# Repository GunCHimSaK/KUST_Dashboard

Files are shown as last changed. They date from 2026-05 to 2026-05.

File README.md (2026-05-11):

# ☀️ KUST 2027 WSC - Dashboard

### Project info

2027 World Solar Challenge (27WSC)를 위한 태양광 자동차 대시보드 펌웨어입니다.

차량 내 핵심 데이터(Driving/Power, Battery BMS)들을 CAN 통신을 통해 데이터를 주고받으며, 주행 정보 및 에러 상태를 실시간으로 계기판 LCD에 띄우고 핸들에서 입력되는 다양한 버튼 데이터들을 각 부분에 전송합니다.

### **System Block Diagram**


### **Dashboard Screen**



### Hardware

- **MCU:** Nucleo U535CE
  
- **Clock:** 160MHz
  
- **IDE:** STM32CubeIDE
  
- **Tool:** LVGL, Square Line Studio
  
- **Communication:** FDCAN (Classic CAN Mode), LPUART1 (115200 bps, Debug)

###

### CAN Matrix

| | CAN ID | Group | Byte0 | Byte1 | Byte2 | Byte3 | Byte4 | Byte5 | Byte6 | Byte7 |
| --- | --- | --- | --- | --- | --- | --- | --- | --- | --- | --- |
| Receive | 0x010 | Fault/Err | Fault Num | Fault Code | 0x00 | 0x00 | 0x00 | 0x00 | 0x00 | 0x00 |
| | 0x100 | Driving/Power | Speed | Recommend Speed | MPPT Power | Motor Power | 0x00 | 0x00 | 0x00 | 0x00 |
| | 0x200 | Status/Information1 | Battery Soc(%) | Battery Signal Bits | Time(Hour) | Time(Min) | 0x00 | 0x00 | 0x00 | 0x00 |
| | 0x201 | Status/Information2 | Info1 Value | Info2 Value | Info3 Value L | Info3 Value H | Info4 Value | 0x00 | 0x00 | 0x00 |
| Transmit | 0x011 | Fault/Err | Fault Num | Fault Code | 0x00 | 0x00 | 0x00 | 0x00 | 0x00 | 0x00 |
| | 0x050 | Control Data | Control Bits | ACC Speed | 0x00 | 0x00 | 0x00 | 0x00 | 0x00 | 0x00 |

| | Bit0 | Bit1 | Bit2 | Bit3 | Bit4 | Bit5 | Bit6 | Bit7 |
| --- | --- | --- | --- | --- | --- | --- | --- | --- |
| Battery Signal Bits | Signal State | Battery State | 0 | 0 | 0 | 0 | 0 | 0 |
| Control Bits | ACC ON/OFF | Test Value1 ON/OFF | Test Value2 ON/OFF | Test Value3 ON/OFF | 0 | 0 | 0 | 0 |

###

### Dashboard CAN Data

| Internal data | Notes | Receive data | Notes | Transmit data | Notes |
| --- | --- | --- | --- | --- | --- |
| Left signal ON/OFF | 0&1 | Speed | 1byte | ACC ON/OFF | 0&1 |
| Right signal ON/OFF | 0&1 | Recommend Speed | 1byte | Test Value1 ON/OFF | 0&1 |
| Hazard ON/OFF | 0&1 | MPPT Power | 1byte(scaling1/10) | Test Value2 ON/OFF | 0&1 |
| ACC ON/OFF | 0&1 | Motor Power | 1byte | Test Value3 ON/OFF | 0&1 |
| Test Value1 ON/OFF | 0&1 | Signal State | 0&1 | Fault Num | 1byte |
| Test Value2 ON/OFF | 0&1 | Battery Soc(%) | 1byte | Fault Code | 1byte |
| Test Value3 ON/OFF | 0&1 | Battery State | 0&1 | | |
| Fault Num | 1byte | Info1 Value | 1byte | | |
| Fault Code | 1byte | Info2 Value | 1byte | | |
| ACC Speed | 1byte | Info3 Value | 2byte | | |
| | | Info4 Value | 1byte | | |
| | | Time | 2byte | | |
| | | Fault Num | 1byte | | |
| | | Fault Code | 1byte | | |

###

### PCB Artwork (26.04.13. Update)


### LED

| **Status Bits** | **LED 1** | **LED 0** | **Status Description** |
| --- | --- | --- | --- |
| 00  | Off | Off | **Normal Operation** |
| 01  | On  | Off | **Error A** |
| 10  | Off | On  | **Error B** |
| 11  | On  | On  | **Fatal Error** |

### Error Code

| **Section** | **Classification** | Remarks |
| --- | --- | --- |
| **00** | | |
| **0x** | | |
| **1x** | | |
| **2x** | | |
| **3x** | | |
| **4x** | | |
| **5x** | | |
| **6x ~ 7x** | | |
| **8x** | | |
| **9x** | | |

### How to run

1. ST-LINK를 통해 보드를 PC와 연결합니다.
  
2. Tera Term 또는 PuTTY 등 시리얼 모니터 프로그램을 실행합니다.
  
  **Baud Rate:** `115200`
  
3. 보드에 전원을 인가하거나 리셋 버튼을 누르면 초기화가 진행됩니다.
  
4. 10초마다 버튼 데이터를 CAN으로 전송하고 수시로 주행데이터를 받아 LCD화면에 값을 표시합니다.

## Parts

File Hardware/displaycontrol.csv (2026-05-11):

Reference | Qty | Value | DNP | Exclude from BOM | Exclude from Board | Footprint | Datasheet | Manufacturer_Name | Manufacturer_Part_Number
C1,C5,C6,C12,C13,C15,C16,C17,C20,C21,C23,C24,C25,C26,C27,C28,C29,C30,C31,C32 | 20 | 100nF/16V/0603 |  |  |  | Capacitor_SMD:C_0603_1608Metric | ~ | Murata Electronics | GCM188R71C104KA37D
C2,C3 | 2 | 8.2pF/16V/0603 |  |  |  | Capacitor_SMD:C_0603_1608Metric | ~ | Murata Electronics | GCM1885C2A8R2BA16D
C4 | 1 | 1uF/16V/0603 | DNP |  |  | Capacitor_SMD:C_0603_1608Metric | ~ | Murata Electronics | GCM188R71E105KA64D
C7,C18 | 2 | 10uF/16V/0805 |  |  |  | Capacitor_SMD:C_0805_2012Metric | ~ | Murata Electronics | GCM21BC71C106KE36K
C8,C9 | 2 | 2.2uF/16V/0805 |  |  |  | Capacitor_SMD:C_0805_2012Metric | ~ | Murata Electronics | GCM21BR71C225KA64L
C10,C14,C19 | 3 | 1uF/16V/0603 |  |  |  | Capacitor_SMD:C_0603_1608Metric | ~ | Murata Electronics | GCM188R71E105KA64D
C11 | 1 | 1uF/16V/0805 |  |  |  | Capacitor_SMD:C_0805_2012Metric | ~ | Murata Electronics | GCM21BR71E105KA56L
C22 | 1 | 4.7nF/16V/0603 |  |  |  | Capacitor_SMD:C_0603_1608Metric | ~ | Murata Electronics | GCM1885C1H472JA16D
CR1 | 1 | ESDALC6V1W5 |  |  |  | BLM18PG601SN1D:SOT65P210X110-5N | https://www.st.com/resource/en/datasheet/esdalc6v1w.pdf | STMicroelectronics | ESDALC6V1W5
D1,D2 | 2 | ESDALC6V1-1U2 |  |  |  | ESDALC6V1-1U2:DIODE_ESDALC6V1-1U2 |  | STMicroelectronics | ESDALC6V1-1U2
D3 | 1 | SM1605E3 |  |  |  | BLM18PG601SN1D:SOIC127P600X175-16N |  | Microchip Technology | SM1605E3/TR13
D4,D5 | 2 | LED |  |  |  | LED_SMD:LED_0603_1608Metric | ~ | Würth Elektronik | 150060VS55040
FB1 | 1 | BLM18PG600SN1D |  |  |  | FH34SRJ-10S-0.5SH:BLM18SP221SN1B | http://www.murata.com/~/media/webrenewal/support/library/catalog/products/emc/emifil/c31e.ashx?la=en-gb | Murata Electronics | BLM18PG600SN1D
J1 | 1 | STLINK |  |  |  | BLM18PG601SN1D:20037WR-05 | ~ | Yeonho | 20037WR-05A00
J3 | 1 | FH34SRJ-10S-0.5SH_50_ |  |  |  | FH34SRJ-10S-0.5SH:HRS_FH34SRJ-10S-0.5SH_50_ |  | Hirose Electric Co Ltd | FH34SRJ-10S-0.5SH(50)
J4 | 1 | Conn_02x05_Odd_Even | DNP |  |  | Connector_PinHeader_2.54mm:PinHeader_2x05_P2.54mm_Vertical | ~
L1 | 1 | 2.2uH/1.3A/2016 |  |  |  | Inductor_SMD:L_0805_2012Metric | ~ | Murata Electronics | LQM21PN2R2MGHL
R1,R7,R8,R12,R13 | 5 | 10K/1%/0603 |  |  |  | Resistor_SMD:R_0603_1608Metric | ~ | Vishay Dale | CRCW060310K0FKEA
R2,R3 | 2 | 47/1%/0603 |  |  |  | Resistor_SMD:R_0603_1608Metric | ~ | Vishay Dale | CRCW060347R0JNEA
R4 | 1 | 470/1%/0603 |  |  |  | Resistor_SMD:R_0603_1608Metric | ~ | Vishay Dale | CRCW0603470RFKEA
R5 | 1 | 910/1%/0603 |  |  |  | Resistor_SMD:R_0603_1608Metric | ~ | Vishay Dale | CRCW0603910RFKEA
R6 | 1 | 1K/1%/0603 |  |  |  | Resistor_SMD:R_0603_1608Metric | ~ | Vishay Dale | CRCW06031K00FKEA
R9,R10,R14,R15,R19,R21,R23,R24,R27,R28,R31,R32 | 12 | 4.7K/1%/0603 |  |  |  | Resistor_SMD:R_0603_1608Metric | ~ | Vishay Dale | CRCW06034K70FKEA
R11,R35 | 2 | 0/1%/0603 |  |  |  | Resistor_SMD:R_0603_1608Metric | ~ | Vishay Dale | CRCW06030000Z0EA
R16,R17 | 2 | 60/1%/0603 |  |  |  | Resistor_SMD:R_0603_1608Metric | ~ | Vishay Dale | CRCW060360R4FKEAC
R18 | 1 | 10k/1%/0603 |  |  |  | Resistor_SMD:R_0603_1608Metric | ~ | Vishay Dale | CRCW060310K0FKEA
R20,R22,R25,R26,R29,R30,R33,R34 | 8 | 100/1%/0603 |  |  |  | Resistor_SMD:R_0603_1608Metric | ~ | Vishay Dale | CRCW0603100RFKEA
R36,R37 | 2 | 300/1%/0603 |  |  |  | Resistor_SMD:R_0603_1608Metric | ~ | Vishay Dale | CRCW0603300RFKEA
SW1,SW2 | 2 | SW_MEC_5E |  |  |  | Button_Switch_SMD:SW_SPST_TL3342 | http://www.apem.com/int/index.php?controller=attachment&id_attachment=1371 | E-Switch | TL3342F260QG
U1 | 1 | STM32U535CET6Q |  |  |  | STM32U535CET6Q:LQFP48-7x7mm_STM | https://www.st.com/resource/en/datasheet/stm32u535cb.pdf | STMicroelectronics | STM32U535CET6Q
U2,U3,U6,U7 | 4 | PC817 |  |  |  | Package_DIP:DIP-4_W7.62mm | http://www.soselectronic.cz/a_info/resource/d/pc817.pdf | SHARP/Socle Technology | PC817X2NSZ9F
U4 | 1 | MR30 |  |  |  | BLM18PG601SN1D:MR30 |  | Changzhou Amass Elec | MR30-FB
U5 | 1 | wr_10p |  |  |  | BLM18PG601SN1D:20037WR-10 |  | Yeonho | 20037WR-10A00
U8 | 1 | wr_03p |  |  |  | BLM18PG601SN1D:20037WR-03 |  | Yeonho | 20037WR-03A00
U9 | 1 | TJA1051T-3 |  |  |  | Package_SO:SOIC-8_3.9x4.9mm_P1.27mm | http://www.nxp.com/docs/en/data-sheet/TJA1051.pdf | NXP USA Inc. | TJA1051T/3/1J
U10 | 1 | wr_06p |  |  |  | BLM18PG601SN1D:20037WR-06 |  | Yeonho | 20037WR-06A00
X1 | 1 | XS00A-CS07826 |  |  |  | DB128V-5.08-2P:XS00A-CS07826 |  | NDK (NIHON DEMPA KOGYO CO., LTD) | CS07826-16M

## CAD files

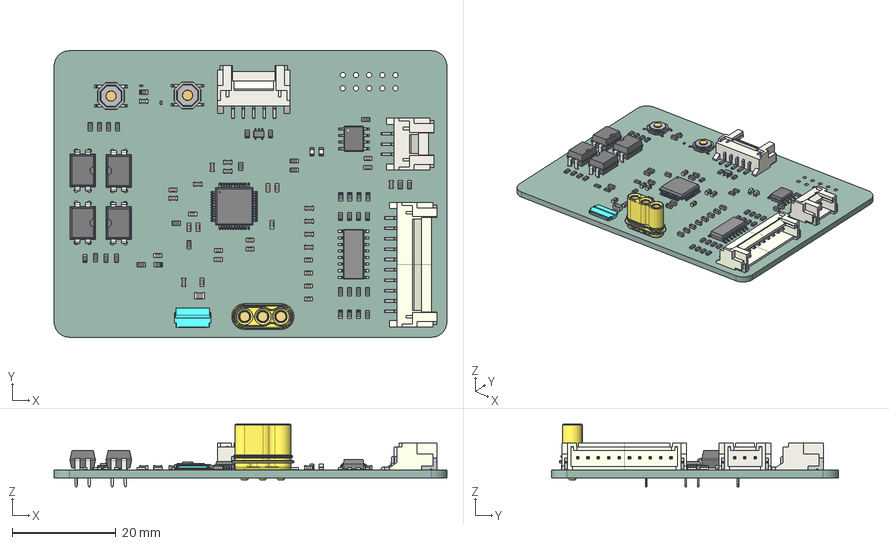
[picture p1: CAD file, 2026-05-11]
Hardware/displaycontrol.step
75.8 x 55.2 x 12.1 mm
R_0603_1608Metric x 37
User Library-20037WR_03
SW_SPST_TL3342 x 2
C_0603_1608Metric x 31
SM1605E3_TR13
LED_0603_1608Metric x 2
ESDALC6V1-1U2 x 2
User Library-20037WR_05
LQFP48-7x7mm_STM_v2
MR30PB-FB
DIP-4_W7.62mm x 4
SOIC-8_3.9x4.9mm_P1.27mm
C_0805_2012Metric
ESDALC6V1W5
FH34SRJ-10S-0.5SH
User Library-20037WR_10
displaycontrol_PCB

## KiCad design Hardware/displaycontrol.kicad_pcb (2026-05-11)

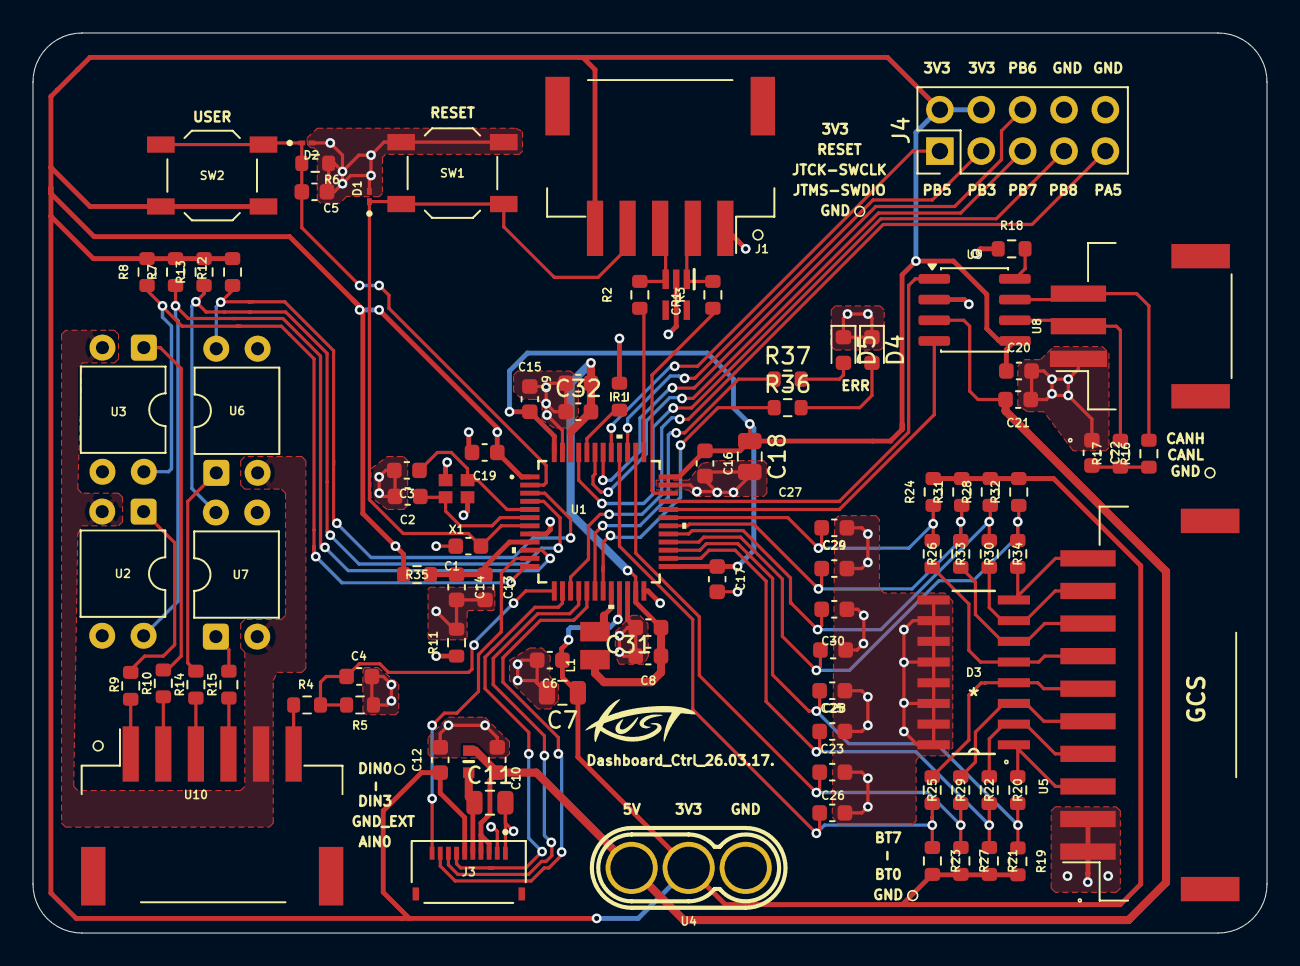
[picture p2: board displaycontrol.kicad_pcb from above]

Board: 2 copper layers, 75.8 x 55.2 mm, 93 parts (0 on the bottom side), 68 nets.

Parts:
C1, C5, C6, C12, C13, C15, C16, C17, C20, C21, C23, C24, C25, C26, C27, C28, C29, C30, C31, C32: 100nF/16V/0603; C_0603_1608Metric
C2, C3: 8.28pF/16V/0603; C_0603_1608Metric
C4, C10, C14, C19: 1uF/16V/0603; C_0603_1608Metric
C7, C18: 10uF/16V/0805; C_0805_2012Metric
C8, C9: 2.2uF/16V/0603; C_0603_1608Metric
C11: 1uF/16V/0603; C_0805_2012Metric
C22: 4.7nF/16V/0603; C_0603_1608Metric
CR1: ESDALC6V1W5; SOT65P210X110-5N
D1, D2: ESDALC6V1-1U2; DIODE_ESDALC6V1-1U2
D3: SM1605E3; SOIC127P600X175-16N
D4, D5: LED; LED_0603_1608Metric
FB1: BLM18PG600SN1D; BLM18SP221SN1B
J1: STLINK; 20037WR-05
J3: FH34SRJ-10S-0.5SH_50_; HRS_FH34SRJ-10S-0.5SH_50_
J4: Conn_02x05_Odd_Even; PinHeader_2x05_P2.54mm_Vertical
L1: 2.2uH/1.5A/2016; INDC2016X100N
R1, R7, R8, R12, R13: 10K/1%/0603; R_0603_1608Metric
R2, R3: 47/1%/0603; R_0603_1608Metric
R4: 470/1%/0603; R_0603_1608Metric
R5: 910/1%/0603; R_0603_1608Metric
R6: 1K/1%/0603; R_0603_1608Metric
R9, R10, R14, R15, R19, R21, R23, R24, R27, R28, R31, R32: 4.7K/1%/0603; R_0603_1608Metric
R11, R35: 0/1%/0603; R_0603_1608Metric
R16, R17: 60/1%/0603; R_0603_1608Metric
R18: 10k/1%/0603; R_0603_1608Metric
R20, R22, R25, R26, R29, R30, R33, R34: 100/1%/0603; R_0603_1608Metric
R36, R37: 300/1%/0603; R_0603_1608Metric
SW1, SW2: SW_MEC_5E; SW_SPST_TL3342
U1: STM32U535CET6Q; LQFP48-7x7mm_STM
U2, U3, U6, U7: PC817; DIP-4_W7.62mm
U4: MR30
U5: wr_10p; 20037WR-10
U8: wr_03p; 20037WR-03
U9: TJA1051T-3; SOIC-8_3.9x4.9mm_P1.27mm
U10: wr_05p; 20037WR-06
X1: XS00A-CS07826

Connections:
+3V3: C6.1, C7.1, C12.1, C15.1, C16.1, C17.1, C18.1, C19.1, C20.1, J1.5, J3.6 (DISP), J4.2, J4.4, R7.2, R8.2, R12.2, R13.2, R19.2, R21.2, R23.2, R24.2, R27.2, R28.2, R31.2, R32.2, R35.1, SW2.1, U1.1 (VBAT), U1.21 (VDDSMPS), U1.25 (VDD), U1.36 (VDD), U1.48 (VDD), U4.2, U9.5 (VIO)
+5V: C10.1, C21.2, FB1.1, J3.3 (EXTMODE), J3.4 (VDD), U4.3, U9.3 (VCC)
+5VA: C11.1, FB1.2, J3.5 (VDDA)
/AIN0: R4.2, U10.6
/CANH: R16.2, U8.3, U9.7 (CANH)
/CANL: R17.2, U8.2, U9.6 (CANL)
/DIN0: R9.1, U10.1
/DIN1: R10.1, U10.2
/DIN2: R14.1, U10.3
/DIN3: R15.1, U10.4
/EXTCOMIN: J3.7 (EXTCOMIN), U1.14 (PA4)
/FDCAN1_RX: U1.32 (PA11), U9.4 (RXD)
/FDCAN1_TX: U1.33 (PA12), U9.1 (TXD)
/JTCK-SWCLK: R2.2, U1.37 (PA14)
/JTMS-SWDIO: R3.1, U1.34 (PA13)
/LED_ERR0: R36.1, U1.19 (PB1)
/LED_ERR1: R37.1, U1.18 (PB0)
/OSC_IN: C3.1, U1.5 (PH0-OSC_IN), X1.3
/OSC_OUT: C2.1, U1.6 (PH1-OSC_OUT), X1.1
/PA5: J4.9, U1.15 (PA5)
/PB3: J4.3, U1.39 (PB3)
/PB5: J4.1, U1.41 (PB5)
/PB6: J4.6, U1.42 (PB6)
/PB7: J4.5, U1.43 (PB7)
/PB8: J4.7, U1.45 (PB8)
/SCLK: J3.10 (SCLK), U1.11 (PA1)
/SCS: J3.8 (SCS), U1.16 (PA6)
/SI: J3.9 (SI), U1.17 (PA7)
/STM_AIN0: C4.1, R4.1, R5.2, U1.13 (PA3)
/STM_Button_0: C24.1, R19.1, R20.1, U1.27 (PB14)
/STM_Button_1: C25.1, R21.1, R22.1, U1.26 (PB13)
/STM_Button_2: C23.1, R27.1, R29.1, U1.38 (PA15)
/STM_Button_3: C26.1, R23.1, R25.1, U1.40 (PB4)
/STM_Button_4: C27.1, R24.1, R26.1, U1.31 (PA10)
/STM_Button_5: C29.1, R31.1, R33.1, U1.30 (PA9)
/STM_Button_6: C28.1, R28.1, R30.1, U1.29 (PA8)
/STM_Button_7: C30.1, R32.1, R34.1, U1.28 (PB15)
/STM_DIN0: R7.1, U1.10 (PA0), U2.4
/STM_DIN1: R8.1, U1.12 (PA2), U3.4
/STM_DIN2: R12.1, U1.3 (PC14-OSC32_IN), U6.4
/STM_DIN3: R13.1, U1.4 (PC15-OSC32_OUT), U7.4
/User Button: C5.1, D2.1, R6.2, SW2.2 (A), U1.2 (PC13)
/VDD11: C8.1, C9.1, C31.1, C32.2, L1.1, U1.23 (VDD11), U1.46 (VDD11)
/VDDA: C13.1, C14.1, R35.2, U1.9 (VDDA)
/VLXSMPS: L1.2, U1.20 (VLXSMPS)
/button_0: D3.1, R20.2, U5.3
/button_1: D3.2, R22.2, U5.4
/button_2: D3.3, R29.2, U5.5
/button_3: D3.4, R25.2, U5.6
/button_4: D3.5, R26.2, U5.7
/button_5: D3.6, R33.2, U5.8
/button_6: D3.7, R30.2, U5.9
/button_7: D3.8, R34.2, U5.10
GND: C1.2, C2.2, C3.2, C5.2, C6.2, C7.2, C8.2, C9.2, C10.2, C12.2, C15.2, C16.2, C17.2, C18.2, C19.2, C20.2, C21.1, C22.1, C23.2, C24.2, C25.2, C26.2, C27.2, C28.2, C29.2, C30.2, C31.2, C32.1, CR1.2, D1.2, D2.2, D3.9, D3.10, D3.11, D3.12, D3.13, D3.14, D3.15, D3.16, D4.1 (K), D5.1 (K), J1.1, J3.2 (VSS), J4.8, J4.10, R1.2, R6.1, R11.1, R18.e, SW1.2 (A), U1.8 (VSSA), U1.22 (VSSSMPS), U1.24 (VSS), U1.35 (VSS), U1.47 (VSS), U2.3, U3.3, U4.1, U5.1, U5.2, U6.3, U7.3, U8.1, U9.ee (GND), X1.2 (GND), X1.4 (GND)
GNDA: C4.2, C11.2, C13.2, C14.2, J3.1 (VSSA), R5.1, R11.2
GND_EXT: U2.2, U3.2, U6.2, U7.2, U10.5
unnamed: C22.2, R16.1, R17.1
unnamed: D4.2 (A), R36.2
unnamed: D5.2 (A), R37.2
unnamed: CR1.1, J1.2, R3.2
unnamed: CR1.3, J1.3, R2.1
unnamed: R9.2, U2.1
unnamed: R10.2, U3.1
unnamed: R14.2, U6.1
unnamed: R15.2, U7.1
unnamed: R1.1, U1.44 (PH3-BOOT0)
unnamed: R18.2, U9.8 (S)
RESET: C1.1, D1.1, J1.4, SW1.1, U1.7 (NRST)

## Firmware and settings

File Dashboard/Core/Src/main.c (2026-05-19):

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
/* Includes ------------------------------------------------------------------*/
#include "main.h"

/* USER CODE BEGIN Includes */
#include <stdio.h>
#include "lvgl.h"
#include "SHARP_MIP.h"
#include "ui.h"
#include "vehicle_data.h"
/* USER CODE END Includes */

ADC_HandleTypeDef hadc1;

FDCAN_HandleTypeDef hfdcan1;

LPTIM_HandleTypeDef hlptim2;

SPI_HandleTypeDef hspi1;
DMA_HandleTypeDef handle_GPDMA1_Channel12;

TIM_HandleTypeDef htim2;

void SystemClock_Config(void);
static void SystemPower_Config(void);
static void MX_GPIO_Init(void);
static void MX_GPDMA1_Init(void);
static void MX_SPI1_Init(void);
static void MX_ADC1_Init(void);
static void MX_FDCAN1_Init(void);
static void MX_LPTIM2_Init(void);
static void MX_TIM2_Init(void);
static void MX_ICACHE_Init(void);
/* USER CODE BEGIN PFP */
void Debug_LED_ShowError(uint8_t errorState);
void Light_Process(void);
void FDCAN_Send_ControlData(void);
/* USER CODE END PFP */

/* USER CODE BEGIN 0 */

void Light_Process(void)
{
	LightData.Left_Signal = (HAL_GPIO_ReadPin(STM_DIN0_GPIO_Port, STM_DIN0_Pin)
			== GPIO_PIN_SET);
	LightData.Right_Signal = (HAL_GPIO_ReadPin(STM_DIN1_GPIO_Port, STM_DIN1_Pin)
			== GPIO_PIN_SET);
	LightData.Hazard_Signal = (HAL_GPIO_ReadPin(STM_DIN2_GPIO_Port,
	STM_DIN2_Pin) == GPIO_PIN_SET);
}

void Dashboard_Update(void)
{
	lv_label_set_text(ui_FaultcodeLabel, "00");
	lv_label_set_text(ui_FaultcodecountLabel, "+0");

	/* 1. 속도 및 권장 속도 매핑 */
	lv_label_set_text_fmt(ui_SpeedLabel, "%d", DrivingData.Speed);
	lv_label_set_text_fmt(ui_RecommendLabel, "%d", DrivingData.Recommend_Speed);

	/* 2. 전력 시스템 및 배터리 정보 */
	lv_label_set_text_fmt(ui_MpptLabel, "%d W", DrivingData.MPPT_Power);
	lv_label_set_text_fmt(ui_MotorLabel, "%d W", DrivingData.Motor_Power);
	lv_label_set_text_fmt(ui_BattaryLabel, "%d%%", DrivingData.Battery_SOC);

	lv_bar_set_value(ui_Bar1, InfoData.Info_4, LV_ANIM_OFF);

	if (DrivingData.Signal_State == true)
	{
		lv_obj_clear_flag(ui_TeleImage, LV_OBJ_FLAG_HIDDEN); // 통신 연결 시 표시
	}
	else
	{
		lv_obj_add_flag(ui_TeleImage, LV_OBJ_FLAG_HIDDEN);   // 통신 끊김 시 숨김
	}

	// 배터리 상태 이상 시 경고 아이콘 노출 제어
	if (DrivingData.Battery_State == false)
	{
		lv_obj_clear_flag(ui_BattarywarnImage, LV_OBJ_FLAG_HIDDEN);
	}
	else
	{
		lv_obj_add_flag(ui_BattarywarnImage, LV_OBJ_FLAG_HIDDEN);
	}

	/* 3. 시스템 상세 정보 (라벨 위젯 연동) */
	lv_label_set_text_fmt(ui_info1unit, "%d %%", InfoData.Info_1);
	lv_label_set_text_fmt(ui_info2unit, "%d W", InfoData.Info_2);
	lv_label_set_text_fmt(ui_info3unit, "%d km", InfoData.Info_3);

	/* 4. 시간 표시 (HH:MM 포맷) */
	static char time_buf[16];
	snprintf(time_buf, sizeof(time_buf), "%02d:%02d", InfoData.Time_Hour,
			InfoData.Time_Min);
	lv_label_set_text(ui_TimeLabel, time_buf);

	/* 5. ACC UI 제어 */
	if (AccData.Acc_state)
	{
		lv_obj_clear_flag(ui_AccImage, LV_OBJ_FLAG_HIDDEN);
		lv_obj_clear_flag(ui_AccUnit, LV_OBJ_FLAG_HIDDEN);
		lv_obj_clear_flag(ui_AccLabel, LV_OBJ_FLAG_HIDDEN);
		lv_label_set_text_fmt(ui_AccLabel, "%d", AccData.Acc_speed);
	}
	else
	{
		lv_obj_add_flag(ui_AccImage, LV_OBJ_FLAG_HIDDEN);
		lv_obj_add_flag(ui_AccUnit, LV_OBJ_FLAG_HIDDEN);
		lv_obj_add_flag(ui_AccLabel, LV_OBJ_FLAG_HIDDEN);
	}

	static uint32_t lastBlinkTick = 0;
	static bool isVisible = false;

	// 일단 무조건 아이콘을 모두 숨김 상태로 시작
	lv_obj_add_flag(ui_Left1Image, LV_OBJ_FLAG_HIDDEN);
	lv_obj_add_flag(ui_Right1Image, LV_OBJ_FLAG_HIDDEN);
	lv_obj_add_flag(ui_HazzardImage, LV_OBJ_FLAG_HIDDEN);

	// 셋 중 하나라도 신호가 들어와 있을 때만 연산 시작!
	if (LightData.Left_Signal || LightData.Right_Signal
			|| LightData.Hazard_Signal)
	{
		// 0.5초가 지났는지 확인
		if (HAL_GetTick() - lastBlinkTick >= 500)
		{
			isVisible = !isVisible;
			lastBlinkTick = HAL_GetTick();
		}

		// 보여줄 타이밍일 때만 아이콘 표시
		if (isVisible)
		{
			if (LightData.Hazard_Signal)
			{
				lv_obj_clear_flag(ui_HazzardImage, LV_OBJ_FLAG_HIDDEN);
				lv_obj_clear_flag(ui_Left1Image, LV_OBJ_FLAG_HIDDEN);
				lv_obj_clear_flag(ui_Right1Image, LV_OBJ_FLAG_HIDDEN);
			}
			else
			{
				if (LightData.Left_Signal)
				{
					lv_obj_clear_flag(ui_Left1Image, LV_OBJ_FLAG_HIDDEN);
				}
				if (LightData.Right_Signal)
				{
					lv_obj_clear_flag(ui_Right1Image, LV_OBJ_FLAG_HIDDEN);
				}
			}
		}
	}
	else
	{
		// 버튼을 모두 떼었을 때: 다음에 버튼을 누르면 즉시 불이 켜지도록 초기화
		isVisible = true;
		lastBlinkTick = HAL_GetTick();
	}
}
/* USER CODE END 0 */

/**
  * @brief  The application entry point.
  * @retval int
  */
int main(void)
{

  /* MCU Configuration--------------------------------------------------------*/

  /* Reset of all peripherals, Initializes the Flash interface and the Systick. */
  HAL_Init();

  /* Configure the System Power */
  SystemPower_Config();

  /* Configure the system clock */
  SystemClock_Config();

  /* Initialize all configured peripherals */
  MX_GPIO_Init();
  MX_GPDMA1_Init();
  MX_SPI1_Init();
  MX_ADC1_Init();
  MX_FDCAN1_Init();
  MX_LPTIM2_Init();
  MX_TIM2_Init();
  MX_ICACHE_Init();
  /* USER CODE BEGIN 2 */
	HAL_FDCAN_ConfigGlobalFilter(&hfdcan1, FDCAN_REJECT, FDCAN_REJECT,
	FDCAN_FILTER_REMOTE, FDCAN_FILTER_REMOTE);

	FDCAN_FilterTypeDef sFilterConfig;

	sFilterConfig.IdType = FDCAN_STANDARD_ID;

	sFilterConfig.FilterIndex = 0;		//filter 1
	sFilterConfig.FilterType = FDCAN_FILTER_DUAL;
	sFilterConfig.FilterConfig = FDCAN_FILTER_TO_RXFIFO0;
	sFilterConfig.FilterID1 = 0x010;
	sFilterConfig.FilterID2 = 0x100;
	HAL_FDCAN_ConfigFilter(&hfdcan1, &sFilterConfig);

	sFilterConfig.FilterIndex = 1;		//filter 2
	sFilterConfig.FilterID1 = 0x200;
	sFilterConfig.FilterID2 = 0x201;
	HAL_FDCAN_ConfigFilter(&hfdcan1, &sFilterConfig);

	HAL_FDCAN_Start(&hfdcan1);
	HAL_FDCAN_ActivateNotification(&hfdcan1, FDCAN_IT_RX_FIFO0_NEW_MESSAGE, 0);

	HAL_LPTIM_PWM_Start(&hlptim2, LPTIM_CHANNEL_1);		//EXTCOMIN Start

	// 2. LVGL 핵심 초기화
	lv_init();

	// 3. 디스플레이 버퍼 및 드라이버 초기화 (SHARP MIP 설정)
	static lv_disp_draw_buf_t draw_buf;
	static uint8_t buf_1[240 * (2 + 320 / 8) + 2]; // Sharp MIP 전용 Oversized 버퍼
	lv_disp_draw_buf_init(&draw_buf, buf_1, NULL, 320 * 240);

	static lv_disp_drv_t disp_drv;
	lv_disp_drv_init(&disp_drv);
	disp_drv.hor_res = 320;
	disp_drv.ver_res = 240;
	disp_drv.flush_cb = sharp_mip_flush;
	disp_drv.rounder_cb = sharp_mip_rounder;
	disp_drv.set_px_cb = sharp_mip_set_px;
	disp_drv.draw_buf = &draw_buf;
	lv_disp_drv_register(&disp_drv);

	// 4. SquareLine UI 초기화
	ui_init();

	Debug_LED_ShowError(0);
  /* USER CODE END 2 */

  /* Infinite loop */
  /* USER CODE BEGIN WHILE */
	while (1)
	{
    /* USER CODE END WHILE */

    /* USER CODE BEGIN 3 */
		Light_Process();			//Light Update
		Dashboard_Update();		//UI Update
		lv_timer_handler();		//LVGL Update
		static uint32_t lastTxTick = 0;
		if (HAL_GetTick() - lastTxTick >= 100)
		{
			FDCAN_Send_ControlData();
			lastTxTick = HAL_GetTick();
		}

		HAL_Delay(5);
	}
  /* USER CODE END 3 */
}

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
/* USER CODE BEGIN 4 */
void HAL_FDCAN_RxFifo0Callback(FDCAN_HandleTypeDef *hfdcan, uint32_t RxFifo0ITs)
{
	FDCAN_RxHeaderTypeDef RxHeader;
	uint8_t RxData[8];

	if (HAL_FDCAN_GetRxMessage(hfdcan, FDCAN_RX_FIFO0, &RxHeader, RxData)
			== HAL_OK)
	{
		switch (RxHeader.Identifier)
		{
		case 0x010: 		//Fault/Err
		{
			uint8_t faultNum = RxData[0];
			uint8_t faultCode = RxData[1];

			if (faultNum > 0 && faultNum < 100)
			{
				Fault_Status[faultNum] = faultCode;
				Fault_Data_Changed = true;
			}
			else if (faultNum == 0)
			{

				Fault_Status[0] = faultCode;
			}
			break;
		}

		case 0x100: 		//Driving/Power
		{
			DrivingData.Speed = RxData[0];
			DrivingData.Recommend_Speed = RxData[1];
			DrivingData.MPPT_Power = RxData[2];
			DrivingData.Motor_Power = RxData[3];
			break;
		}

		case 0x200: 		//Status/Information1
		{
			DrivingData.Battery_SOC = RxData[0];

			DrivingData.Signal_State = (RxData[1] & 0x01) ? true : false; // Bit 0
			DrivingData.Battery_State = (RxData[1] & 0x02) ? true : false; // Bit 1

			InfoData.Time_Hour = RxData[2];
			InfoData.Time_Min = RxData[3];
			break;
		}

		case 0x201: 		//Status/Information2
		{
			InfoData.Info_1 = RxData[0];
			InfoData.Info_2 = RxData[1];

			InfoData.Info_3 = (uint16_t) ((RxData[3] << 8) | RxData[2]);

			InfoData.Info_4 = RxData[4];
			break;
		}
		}
	}
}
/* 디버깅 LED 에러 표시 함수 */
void Debug_LED_ShowError(uint8_t errorState)
{
	switch (errorState)
	{
	case 0: // 00 : 정상 상태 (모두 꺼짐)
	{
		HAL_GPIO_WritePin(LED_ERR1_GPIO_Port, LED_ERR1_Pin, GPIO_PIN_RESET);
		HAL_GPIO_WritePin(LED_ERR0_GPIO_Port, LED_ERR0_Pin, GPIO_PIN_RESET);
		break;
	}
	case 1: // 01 : 에러 상태 1 (ERR1 켜짐, ERR0 꺼짐)
	{
		HAL_GPIO_WritePin(LED_ERR1_GPIO_Port, LED_ERR1_Pin, GPIO_PIN_SET);
		HAL_GPIO_WritePin(LED_ERR0_GPIO_Port, LED_ERR0_Pin, GPIO_PIN_RESET);
		break;
	}
	case 2: // 10 : 에러 상태 2 (ERR1 꺼짐, ERR0 켜짐)
	{
		HAL_GPIO_WritePin(LED_ERR1_GPIO_Port, LED_ERR1_Pin, GPIO_PIN_RESET);
		HAL_GPIO_WritePin(LED_ERR0_GPIO_Port, LED_ERR0_Pin, GPIO_PIN_SET);
		break;
	}
	case 3: // 11 : 에러 상태 3 (모두 켜짐 - 크리티컬 에러)
	{
		HAL_GPIO_WritePin(LED_ERR1_GPIO_Port, LED_ERR1_Pin, GPIO_PIN_SET);
		HAL_GPIO_WritePin(LED_ERR0_GPIO_Port, LED_ERR0_Pin, GPIO_PIN_SET);
		break;
	}
	default: // 예외 처리 (혹시 모를 값 방지, 모두 꺼짐)
	{
		HAL_GPIO_WritePin(LED_ERR1_GPIO_Port, LED_ERR1_Pin, GPIO_PIN_RESET);
		HAL_GPIO_WritePin(LED_ERR0_GPIO_Port, LED_ERR0_Pin, GPIO_PIN_RESET);
		break;
	}
	}
}

void HAL_GPIO_EXTI_Callback(uint16_t GPIO_Pin)
{
	// ACC ON/OFF 토글 (버튼 0)
	if (GPIO_Pin == STM_Button_0_Pin)
	{
		AccData.Acc_state = !AccData.Acc_state;
	}

	// ACC 속도 조절은 ACC가 ON 상태일 때만 동작
	else if (AccData.Acc_state)
	{
		// 속도 UP (버튼 1)
		if (GPIO_Pin == STM_Button_1_Pin)
		{
			AccData.Acc_speed++;
		}
		// 속도 DOWN (버튼 2)
		else if (GPIO_Pin == STM_Button_2_Pin)
		{
			if (AccData.Acc_speed > 0)
			{
				AccData.Acc_speed--;
			}
		}
	}
}

void FDCAN_Send_ControlData(void)
{
	FDCAN_TxHeaderTypeDef TxHeader;
	uint8_t TxData[8] =
	{ 0, }; // 배열을 0으로 싹 초기화 (Data[2]~[7]은 자동으로 0x00이 됨)

	// 송신 헤더 설정 (표에 맞춰 ID 0x050 설정)
	TxHeader.Identifier = 0x050;
	TxHeader.IdType = FDCAN_STANDARD_ID;
	TxHeader.TxFrameType = FDCAN_DATA_FRAME;
	TxHeader.DataLength = FDCAN_DLC_BYTES_8;
	TxHeader.ErrorStateIndicator = FDCAN_ESI_ACTIVE;
	TxHeader.BitRateSwitch = FDCAN_BRS_OFF;
	TxHeader.FDFormat = FDCAN_CLASSIC_CAN;
	TxHeader.TxEventFifoControl = FDCAN_NO_TX_EVENTS;
	TxHeader.MessageMarker = 0;

	/* 1. Control Bits (Data[0]) 조합 */
	// 비트 시프트(<<) 와 OR 연산(|)을 이용해 1바이트 안에 여러 bool 값을 우겨넣습니다.
	// LSB(우측 끝)부터 비트 0으로 시작합니다.
	if (AccData.Acc_state)
	{
		TxData[0] |= (1 << 0); // Bit 0
	}
	if (InfoData.Test_Value1)
	{
		TxData[0] |= (1 << 1); // Bit 1
	}
	if (InfoData.Test_Value2)
	{
		TxData[0] |= (1 << 2); // Bit 2
	}
	if (InfoData.Test_Value3)
	{
		TxData[0] |= (1 << 3); // Bit 3
	}

	/* 2. ACC Speed (Data[1]) */
	TxData[1] = AccData.Acc_speed;

	/* 3. CAN 메시지 송신 */
	// 메일박스(Tx FIFO)에 남은 공간이 있는지 안전하게 확인 후 전송
	if (HAL_FDCAN_GetTxFifoFreeLevel(&hfdcan1) > 0)
	{
		HAL_FDCAN_AddMessageToTxFifoQ(&hfdcan1, &TxHeader, TxData);
	}
}

extern lv_disp_drv_t * active_disp_drv;

/**
  * @brief  SPI 전송 완료 콜백 (DMA 전송이 완료되면 자동 호출됨)
  * @param  hspi: SPI handle
  * @retval None
  */
void HAL_SPI_TxCpltCallback(SPI_HandleTypeDef *hspi)
{
    /* 우리가 화면을 그리는 데 사용하는 SPI1이 맞는지 확인 */
    if (hspi->Instance == SPI1)
    {
        /* 1. 전송이 완료되었으므로 CS 핀 비활성화 (LOW) */
        HAL_GPIO_WritePin(SPI1_SCS_GPIO_Port, SPI1_SCS_Pin, GPIO_PIN_RESET);

        /* 2. LVGL에 프레임 버퍼 전송이 완료되었음을 보고 */
        if (active_disp_drv != NULL)
        {
            lv_disp_flush_ready(active_disp_drv);
            active_disp_drv = NULL; /* 다음 프레임을 위해 포인터 초기화 */
        }
    }
}

/* USER CODE END 4 */
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


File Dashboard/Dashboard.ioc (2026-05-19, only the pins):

Mcu.UserName=STM32U535CETxQ
PA0.GPIO_Label=STM_DIN0
PA0.Signal=GPIO_Input
PA1.Signal=SPI1_SCK
PA10.GPIO_Label=STM_Button_4
PA10.Signal=GPIO_Input
PA11.Signal=FDCAN1_RX
PA12.Signal=FDCAN1_TX
PA2.GPIO_Label=STM_DIN1
PA2.Signal=GPIO_Input
PA3.GPIO_Label=STM_AIN0
PA3.Signal=ADC1_IN8
PA4.GPIO_Label=EXTCOMIN
PA4.Signal=S_LPTIM2_CH1
PA6.GPIO_Label=SPI1_SCS
PA6.Signal=GPIO_Output
PA7.Signal=SPI1_MOSI
PA8.GPIO_Label=STM_Button_6
PA8.Signal=GPIO_Input
PA9.GPIO_Label=STM_Button_5
PA9.Signal=GPIO_Input
PB0.GPIO_Label=LED_ERR1
PB0.Signal=GPIO_Output
PB1.GPIO_Label=LED_ERR0
PB1.Signal=GPIO_Output
PB13.GPIO_Label=STM_Button_1
PB13.Signal=GPXTI13
PB14.GPIO_Label=STM_Button_0
PB14.Signal=GPXTI14
PB15.GPIO_Label=STM_Button_7
PB15.Signal=GPIO_Input
PC13.GPIO_Label=User_Button
PC13.Signal=GPIO_Input

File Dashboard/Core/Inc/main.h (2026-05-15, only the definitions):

#define User_Button_Pin GPIO_PIN_13
#define User_Button_GPIO_Port GPIOC
#define STM_DIN2_Pin GPIO_PIN_14
#define STM_DIN2_GPIO_Port GPIOC
#define STM_DIN3_Pin GPIO_PIN_15
#define STM_DIN3_GPIO_Port GPIOC
#define STM_DIN0_Pin GPIO_PIN_0
#define STM_DIN0_GPIO_Port GPIOA
#define STM_DIN1_Pin GPIO_PIN_2
#define STM_DIN1_GPIO_Port GPIOA
#define STM_AIN0_Pin GPIO_PIN_3
#define STM_AIN0_GPIO_Port GPIOA
#define EXTCOMIN_Pin GPIO_PIN_4
#define EXTCOMIN_GPIO_Port GPIOA
#define SPI1_SCS_Pin GPIO_PIN_6
#define SPI1_SCS_GPIO_Port GPIOA
#define LED_ERR1_Pin GPIO_PIN_0
#define LED_ERR1_GPIO_Port GPIOB
#define LED_ERR0_Pin GPIO_PIN_1
#define LED_ERR0_GPIO_Port GPIOB
#define STM_Button_1_Pin GPIO_PIN_13
#define STM_Button_1_GPIO_Port GPIOB
#define STM_Button_1_EXTI_IRQn EXTI13_IRQn
#define STM_Button_0_Pin GPIO_PIN_14
#define STM_Button_0_GPIO_Port GPIOB
#define STM_Button_0_EXTI_IRQn EXTI14_IRQn
#define STM_Button_7_Pin GPIO_PIN_15
#define STM_Button_7_GPIO_Port GPIOB
#define STM_Button_6_Pin GPIO_PIN_8
#define STM_Button_6_GPIO_Port GPIOA
#define STM_Button_5_Pin GPIO_PIN_9
#define STM_Button_5_GPIO_Port GPIOA
#define STM_Button_4_Pin GPIO_PIN_10
#define STM_Button_4_GPIO_Port GPIOA
#define STM_Button_2_Pin GPIO_PIN_15
#define STM_Button_2_GPIO_Port GPIOA
#define STM_Button_2_EXTI_IRQn EXTI15_IRQn
#define STM_Button_3_Pin GPIO_PIN_4
#define STM_Button_3_GPIO_Port GPIOB

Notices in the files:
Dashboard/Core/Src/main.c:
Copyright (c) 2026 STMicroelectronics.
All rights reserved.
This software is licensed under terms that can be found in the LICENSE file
